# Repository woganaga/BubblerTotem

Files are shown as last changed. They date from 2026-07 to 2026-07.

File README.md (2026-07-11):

# BubblerTotem

Bubble-LED-Rage-Totem: a battery-powered LED totem / bubble machine — 6
stacked rings of 27 WS2811 LEDs (162 total, an unrolled 27×6 cylinder) plus a
bubble motor, driven by an ESP32-S3 with an INMP441 I2S microphone for
sound-reactive effects.

The firmware is a customized fork of
[WLED-MM (MoonModules)](https://github.com/MoonModules/WLED-MM), chosen for
its advanced audio visualizations.

## Project layout

| Path | Status | What it is |
|---|---|---|
| [`WLED-MM/`](WLED-MM/) | **active** | Firmware: WLED-MM fork (git submodule, branch `bubbler`). Totem customizations live in its `bubbler/` folder + usermods. |
| [`BubblerAnalyzer/`](BubblerAnalyzer/) | active | Offline audio/beat-detection analysis: pulls synchronized mic WAV + DSP metadata captures from the device over WiFi and diffs the pipeline against an offline replica. |
| [`docs/`](docs/) | active (port pending) | Web Bluetooth control app (GitHub Pages). Built for the v1 firmware; will be reworked once WLED-MM gets its BLE usermod. |
| [`archive/Bubbler-pio/`](archive/Bubbler-pio/) | retired | v1 custom firmware (PlatformIO): effects engine, palettes/presets, BLE protocol, beat detection. Superseded by the WLED-MM fork; kept as reference — the beat-detection work (comb tempo picker) and BLE chunk protocol are worth porting. |
| [`archive/BubblerIno/`](archive/BubblerIno/) | retired | Original Arduino IDE sketch (v0). |

## Working with the firmware submodule

```sh
git clone --recurse-submodules https://github.com/woganaga/BubblerTotem.git
cd BubblerTotem/WLED-MM
# copy bubbler/platformio_bubbler.sample.ini -> platformio_override.ini, add WiFi creds
pio run -e bubbler_totem
```

The submodule's `origin` is the `woganaga/WLED-MM` fork; `upstream` is
MoonModules. Custom work stays on the `bubbler` branch in low-collision
surfaces (`bubbler/`, usermods, the gitignored `platformio_override.ini`) so
upstream merges stay painless.

## Hardware map

| Function | GPIO |
|---|---|
| LED chain A (rings 3,2,1 — 81 px, WS2811 GRB) | 4 |
| LED chain B (rings 4,5,6 — 81 px) | 5 |
| INMP441 mic SCK / WS / SD | 44 / 7 / 8 |
| Bubble motor (planned) | 15 |
| RS485 command receiver (planned) | 1, 2, 42 |
| Onboard status LED (active low) | 21 |

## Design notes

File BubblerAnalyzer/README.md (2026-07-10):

# BubblerAnalyzer

Offline analysis of the totem's beat-detection pipeline, using synchronized
captures (raw mic WAV + per-frame DSP metadata CSV) pulled from the device
over WiFi.

## Workflow

1. Make sure the totem is on WiFi (`bubblertotem.local`) and, for musical
   tests, that the test material is playing at show volume.
2. Pull a capture:
   ```powershell
   .\capture.ps1 -Seconds 30          # clamped 5..30 by the firmware
   ```
   This triggers `/action/mic/record`, polls `/api/status`, and downloads
   `mic_recording.wav` + `mic_meta.csv` into `captures\<timestamp>\`.
3. Analyze (requires Python 3 + numpy + matplotlib):
   ```powershell
   py analyze.py captures\<timestamp> --bpm 160   # --bpm = ground truth, if known
   ```

`analyze.py` replicates the firmware pipeline (`AudioInput.cpp`: Hann FFT ->
log-compressed spectral flux -> conditioned onset envelope -> zero-mean
normalized autocorrelation -> harmonic-weighted tempo pick) on the recorded
audio and diffs it against what the device logged for the same instants:

- signal quality (peak/RMS dBFS, clipping, DC)
- onset envelope shape, offline vs device flux correlation
- ACF offline vs the device's final ACF snapshot
- tempo/confidence traces over time vs the device's, against ground truth

Plots land in the capture folder as `analysis.png`. Divergence between the
offline replica and the device log points at the broken stage; agreement
means the algorithm (not the implementation) needs work.

Captures are gitignored (a 30s WAV is ~1MB).

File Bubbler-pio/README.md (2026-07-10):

# Bubbler Totem

Firmware for a music-reactive LED totem: 6 stacked rings of 27 WS2811 LEDs
(162 total) driven by an ESP32-S3. The primary control interface is Web
Bluetooth (see below); WiFi/HTTP is a secondary, opt-in interface used
mainly for firmware updates.

This is the PlatformIO project. It was ported from the original Arduino IDE
sketch at `../BubblerIno`, which is no longer the active codebase.

## Hardware

- **MCU:** ESP32-S3 (8MB flash, dual-app OTA partition layout)
- **LEDs:** 6 rings × 27 WS2811 pixels, wired as two chains of 3 rings each
  - Pin 4: rings 3, 2, 1
  - Pin 5: rings 4, 5, 6
  - Physical layout/spacing lives in `Topology.*`; LED brightness is capped
    per-pixel (40%) and per-array (15%) in `Rings.cpp` to keep current draw
    in check.
- **Mic:** INMP441 I2S microphone
  - Pin 44: SCK, Pin 7: WS, Pin 8: SD
- **Status LED:** GPIO 21 (active low) — blinks in real time with the PLL
  beat clock once a tempo is tracked (raw onsets before that), so the beat
  tracker can be eyeballed against the music with no UI polling latency

## Features

- **Effects** (`EffectManager.*`, `Effects.*`): 12 original effects (Vertical/
  Horizontal Sweep, Alternate Flash, Chase, Spiral, Snow, Pinwheel, Colorwash,
  Fire, Confetti, Ripple) plus a **Beat Flash** test effect (whole array
  flashes and decays once per period — a metronome for the eyes; run it with
  Beat Sync at 1 beat/cycle to see exactly what the tempo tracker is doing)
  plus 8 effects ported from xLights (`XLFX.*`) that
  render onto the ring array treated as an unrolled 27×6 grid (Bars,
  Colorwash, Spirals, Pinwheel, Butterfly, Plasma, SingleStrand, Morph). Each
  effect keeps its own parameters (palette, speed, intensity, direction, and
  effect-specific controls) across activations.
- **Music reactivity** (`AudioInput.*`): a FreeRTOS task pinned to core 0 runs
  a 512-sample Hann-windowed FFT over the mic input, publishing a lock-free
  `AudioFeatures` snapshot — bass/mid/treble energy, smoothed volume, beat
  detection, and a BPM estimate (autocorrelation of the onset envelope + a
  PLL beat clock) with tap-tempo and ×2/÷2 override. **Beat Sync** (toggle on
  the Main tab) tempo-locks the running effect: once the tempo estimator is
  confidently locked, `EffectManager` stops feeding the effect real elapsed
  time and synthesizes its time input from the PLL beat clock, scaled so one
  full effect cycle spans exactly N beats (N auto-picked from ½/1/2/4/8 to
  best match the effect's speed setting, or fixed via the Beats-per-cycle
  buttons) with cycle boundaries landing on beats. The animation speeds up,
  slows down, and stays in phase with the music indefinitely — no per-effect
  changes needed, since each periodic effect is a pure function of its time
  argument and exposes its natural cycle length via
  `effectNativePeriodMs()`/`xlfxNativePeriodMs()`. Stochastic effects with no
  fixed loop (Snow, Fire, Confetti, Ripple, XL Butterfly, XL Plasma)
  free-run; while no confident tempo is detected, everything free-runs (with
  hysteresis so borderline confidence doesn't flap between modes). The Main
  tab shows a live readout of the lock state, and the status bar visualizes
  the tracker at a glance: detected-onset dot, a pulse dot that beats at the
  detected BPM (amber while unlocked, green when sync is locked — re-phased
  to the device's beat clock on every status poll), BPM + lock confidence,
  and a ♪×N badge showing the locked beats-per-cycle. A **Mic Recording** button
  (Settings tab, both transports) captures
  a fixed 10 seconds of raw mic audio to a `.wav` file on LittleFS, so you can
  judge how noisy the mic/preamp actually is by listening back. Triggering
  the recording works over BLE or WiFi, but the finished file (~320KB) is
  only downloadable over WiFi/HTTP — pushing that much data through the BLE
  chunk protocol above would be impractically slow.
- **Named palettes & saved effect presets** (`PaletteStore.*`,
  `CategoryStore.*`, `EffectPresetStore.*`): color palettes are created,
  edited, and deleted independently of any one effect, then *linked* to
  whichever effect is showing them (edit a palette and any effect currently
  using it updates live). A full effect configuration (type + palette link +
  params) can be named, categorized, and saved as a preset for one-tap
  recall later. All persisted to LittleFS.
- **Bluetooth control (primary interface)** (`BleServer.*`): a custom BLE
  GATT service (one write characteristic for commands, one notify
  characteristic for chunked JSON responses) exposes the full control
  surface — effects, palettes, presets, categories, mic calibration, WiFi
  on/off — to the standalone Web Bluetooth app at
  [`../docs/index.html`](../docs/index.html) (meant to be published somewhere
  HTTPS, e.g. GitHub Pages — Web Bluetooth requires a secure context and
  doesn't work from the device's own plain-HTTP page). **Safari on iOS/macOS
  does not support Web Bluetooth at all** (Apple's stated position, not a
  bug) — on iPhone, use a bridge browser like
  [Bluefy](https://apps.apple.com/app/bluefy-web-ble-browser/id1492822055)
  or WebBLE instead; desktop/Android Chrome and Edge work directly.
- **Web UI over WiFi** (`WebUI.*`, `WebApp.*`), a secondary interface served
  on port 80 once WiFi is on — a single-page app with the same Main/Effects/
  Saved/Palettes/Settings sections as the BLE app, plus a **Firmware Update**
  page under Settings that only shows up here (not over BLE, since pushing a
  multi-hundred-KB binary over BLE characteristics isn't practical).
- **WiFi** (`WifiSetup.*`): station mode, **off by default** — BLE is the
  primary interface, so the radio only comes on when explicitly enabled
  (toggle lives in the BLE app's Settings tab; the on/off choice persists to
  LittleFS across reboots). SSID/password live in `src/Secrets.h` (gitignored
  — copy `src/Secrets.h.example` to `src/Secrets.h` and fill in your network
  before building).
- **OTA updates** (`OTAUpdate.*`): `ArduinoOTA`, password-protected, an
  alternative to the WiFi web UI's Firmware Update page — both require WiFi
  to be turned on first.

## Building & flashing

Requires [PlatformIO](https://platformio.org/). This project uses the
[pioarduino](https://github.com/pioarduino/platform-espressif32) community
platform instead of the official `espressif32` platform, because it tracks
arduino-esp32 core 3.x — the official platform is still on core 2.x and
lacks the `ESP_I2S.h` API the mic driver depends on.

Before the first build, copy `src/Secrets.h.example` to `src/Secrets.h` and
fill in your WiFi SSID/password (that file is gitignored, so it won't be
committed).

```sh
pio run                 # build (default env: esp32-s3-devkitc-1-debug)
pio run -t upload       # build + flash over USB
pio run -t uploadfs     # push the LittleFS filesystem (mic settings, etc.)
pio device monitor      # serial monitor
```

There are three environments (`platformio.ini`):
- **`esp32-s3-devkitc-1-debug`** — the current default (`pio run` with no
  `-e` builds this). Same as the plain env, plus verbose BLE wire-protocol
  tracing (every chunk/ack/command) to the Serial monitor, gated behind
  `BUBBLER_BLE_DEBUG` (see `BLE_LOG` in `BleServer.cpp`).
- **`esp32-s3-devkitc-1`** — the quiet build, no BLE tracing. Once BLE is
  solid, build this explicitly (`pio run -e esp32-s3-devkitc-1 -t upload`),
  or flip `default_envs` in `platformio.ini` back to it.
- **`esp32-s3-devkitc-1-ota`** — OTA upload variant (extends the plain env).

Once the device is on the network, subsequent updates can go over OTA
(`espota`) or the WiFi web UI's Firmware Update page instead of USB. WiFi
being off by default means the very first flash (and any time it's been
turned off since) has to be over USB.

## Setting up the Bluetooth app

`../docs/index.html` (at the repo root, a sibling of this `Bubbler-pio`
folder — GitHub Pages' "/docs" option is relative to the repo root, not any
subfolder) is a standalone static page — it isn't served by the device.
Publish it somewhere HTTPS (Web Bluetooth requires that) and bookmark it on
your phone/laptop:

1. GitHub repo → **Settings → Pages** → Source: "Deploy from a branch" →
   branch `main`, folder `/docs` → Save.
2. GitHub gives you a URL like `https://<user>.github.io/BubblerTotem/`.
   Open it, tap **Connect**, and pick "BubblerTotem" from the Bluetooth
   device list.
3. On iPhone, do this inside Bluefy or WebBLE (not Safari) — see the Web UI
   note above.

## Project layout

```
../docs/index.html   standalone Web Bluetooth app, at the repo root (publish via GitHub Pages)
platformio.ini       build config (board, pioarduino platform, lib_deps)
partitions.csv        8MB flash partition table (dual OTA app slots + LittleFS)
src/
  main.cpp            setup()/loop()
  Rings.*              LED buffer, ring addressing, brightness caps
  Topology.*            physical ring spacing/geometry
  EffectManager.*       active effect + per-effect param/palette-link storage/dispatch
  EffectUI.*            per-effect-type UI capability table, shared by WebUI and BleServer
  Effects.*             original effects
  XLFX.*                xLights-derived effects
  Palette.h / Color.h / EffectParams.h   shared color/param types
  PaletteStore.*         named/saved color palettes (LittleFS)
  CategoryStore.*        named categories for saved effects (LittleFS)
  EffectPresetStore.*     named/saved effect configurations (LittleFS)
  AudioInput.*          I2S mic capture, FFT/DSP task, beat/BPM detection
  BleServer.*           Web Bluetooth GATT service + JSON command dispatch (primary interface)
  WebUI.* / WebApp.*     WiFi HTTP server + single-page app (secondary interface)
  WifiSetup.*           WiFi station connect, off by default, persisted on/off toggle
  OTAUpdate.*           ArduinoOTA
```

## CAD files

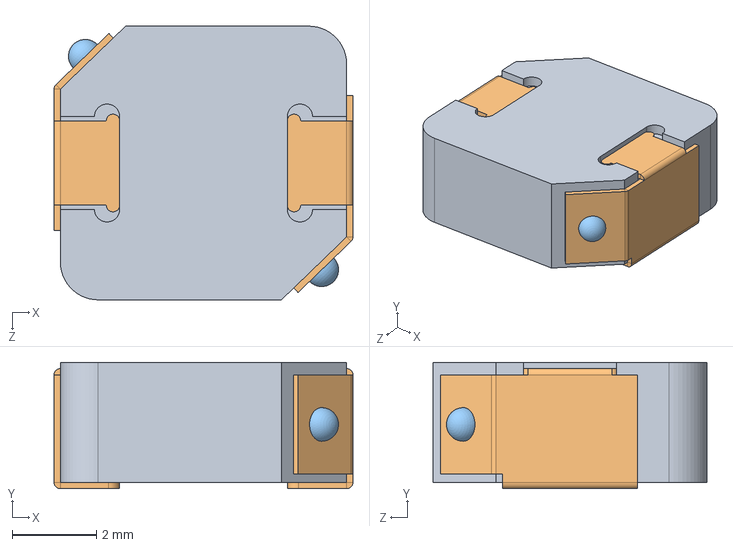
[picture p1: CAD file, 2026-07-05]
BubblerMain/SPM6530T-3R3M.step
7.10 x 3.00 x 6.50 mm

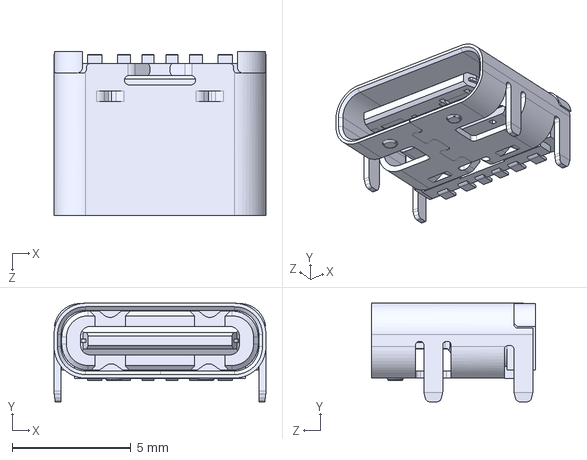
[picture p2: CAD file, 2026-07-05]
BubblerMain/UJC-H-G-SMT-P6-TR.step
8.94 x 4.16 x 6.90 mm

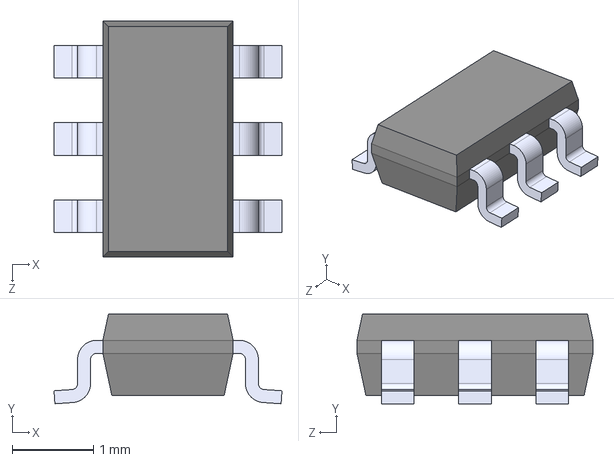
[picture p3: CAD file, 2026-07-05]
BubblerMain/TPS565201DDCR.step
2.80 x 1.10 x 2.90 mm

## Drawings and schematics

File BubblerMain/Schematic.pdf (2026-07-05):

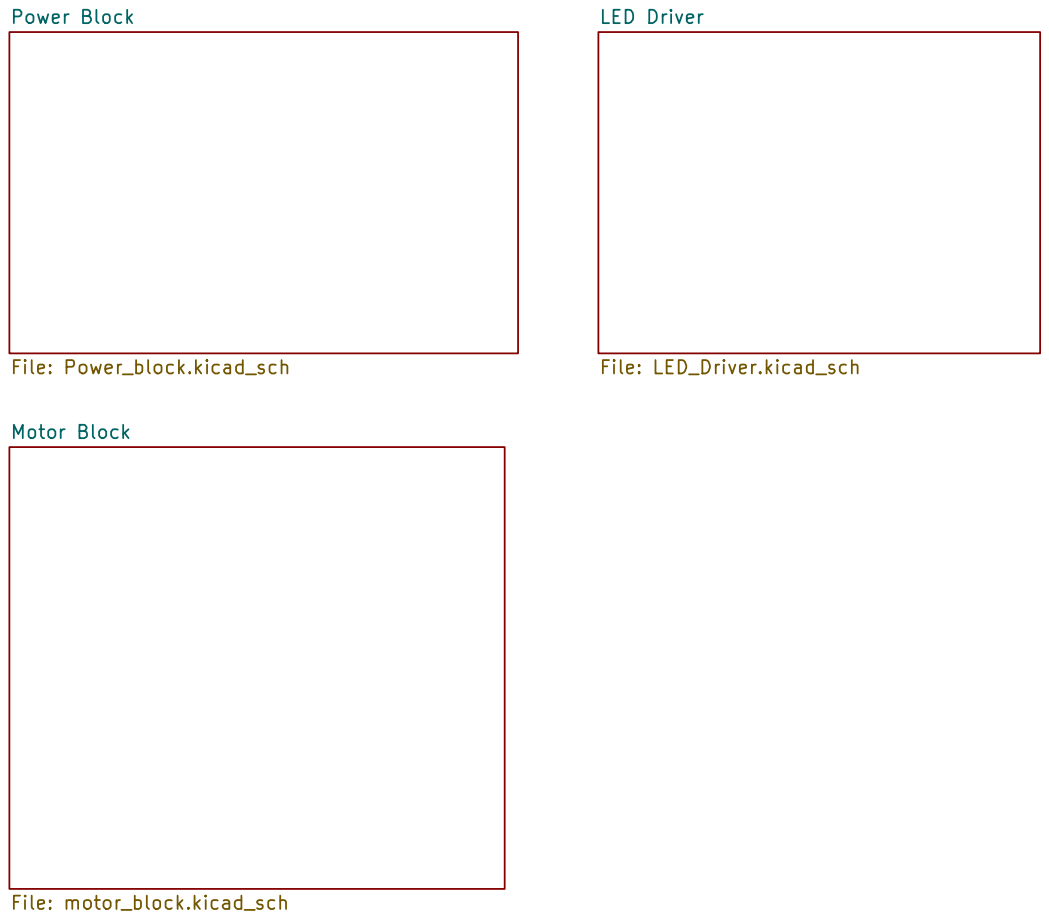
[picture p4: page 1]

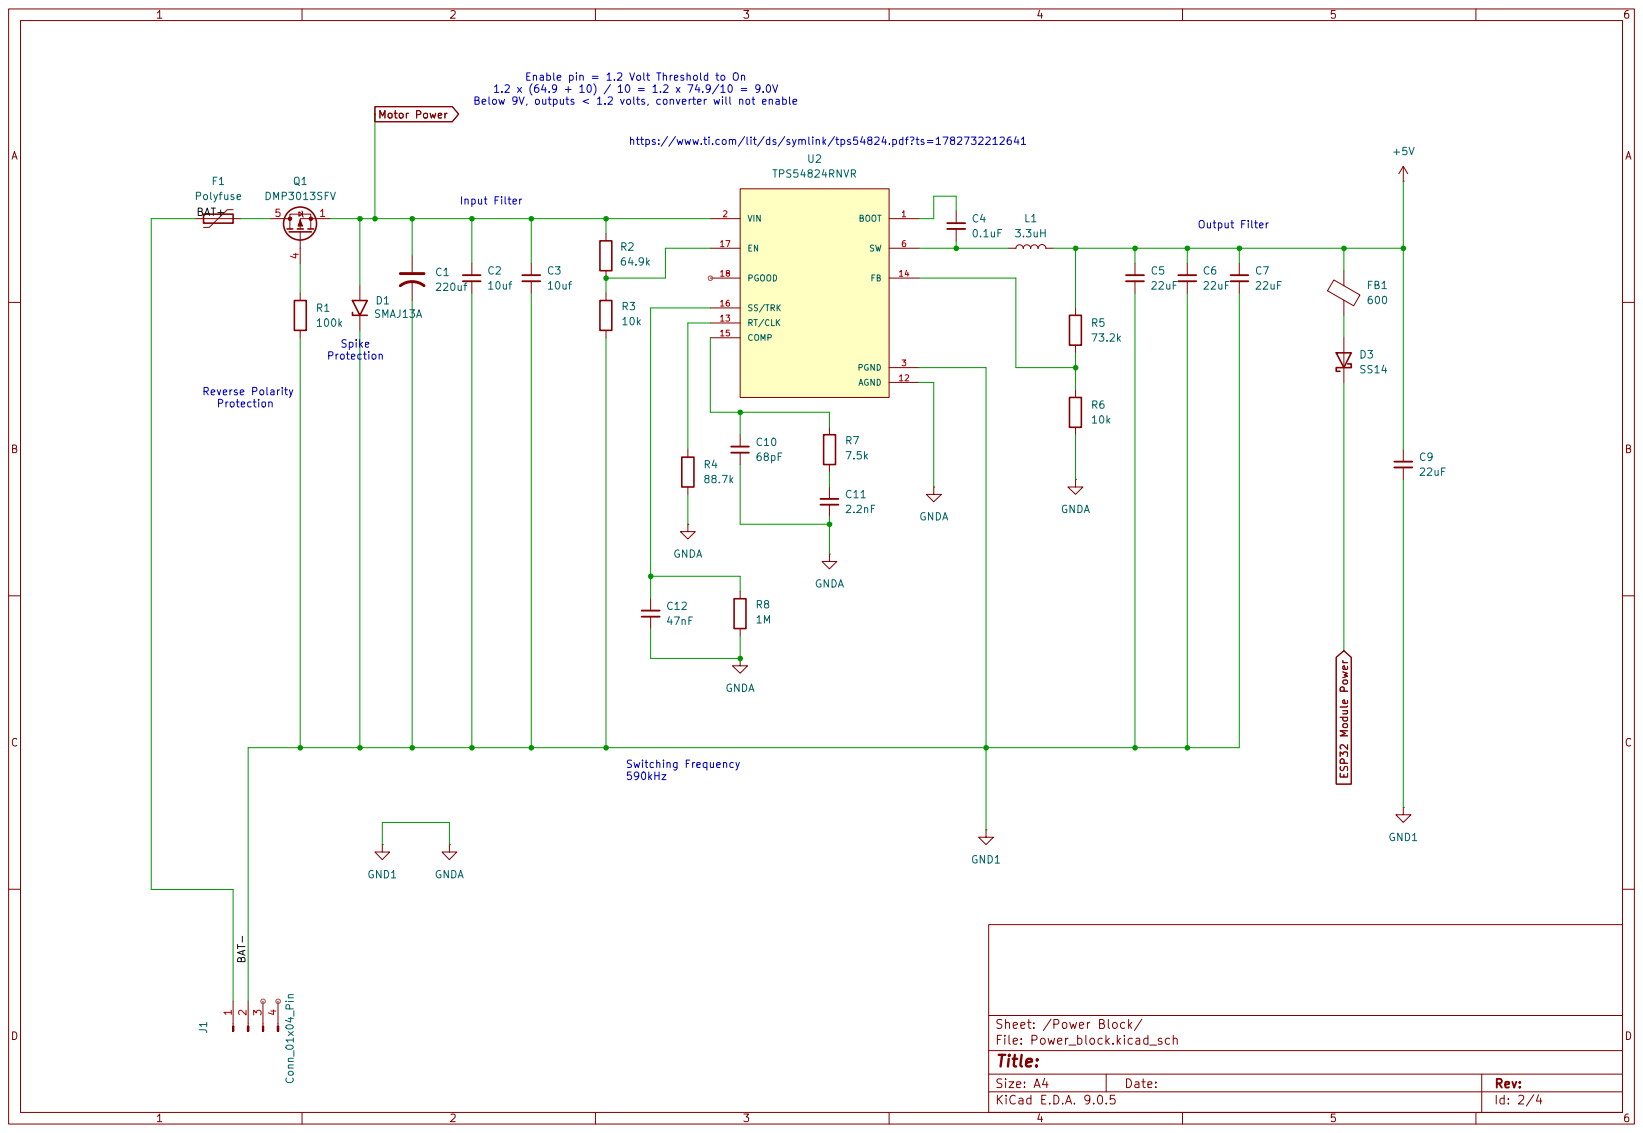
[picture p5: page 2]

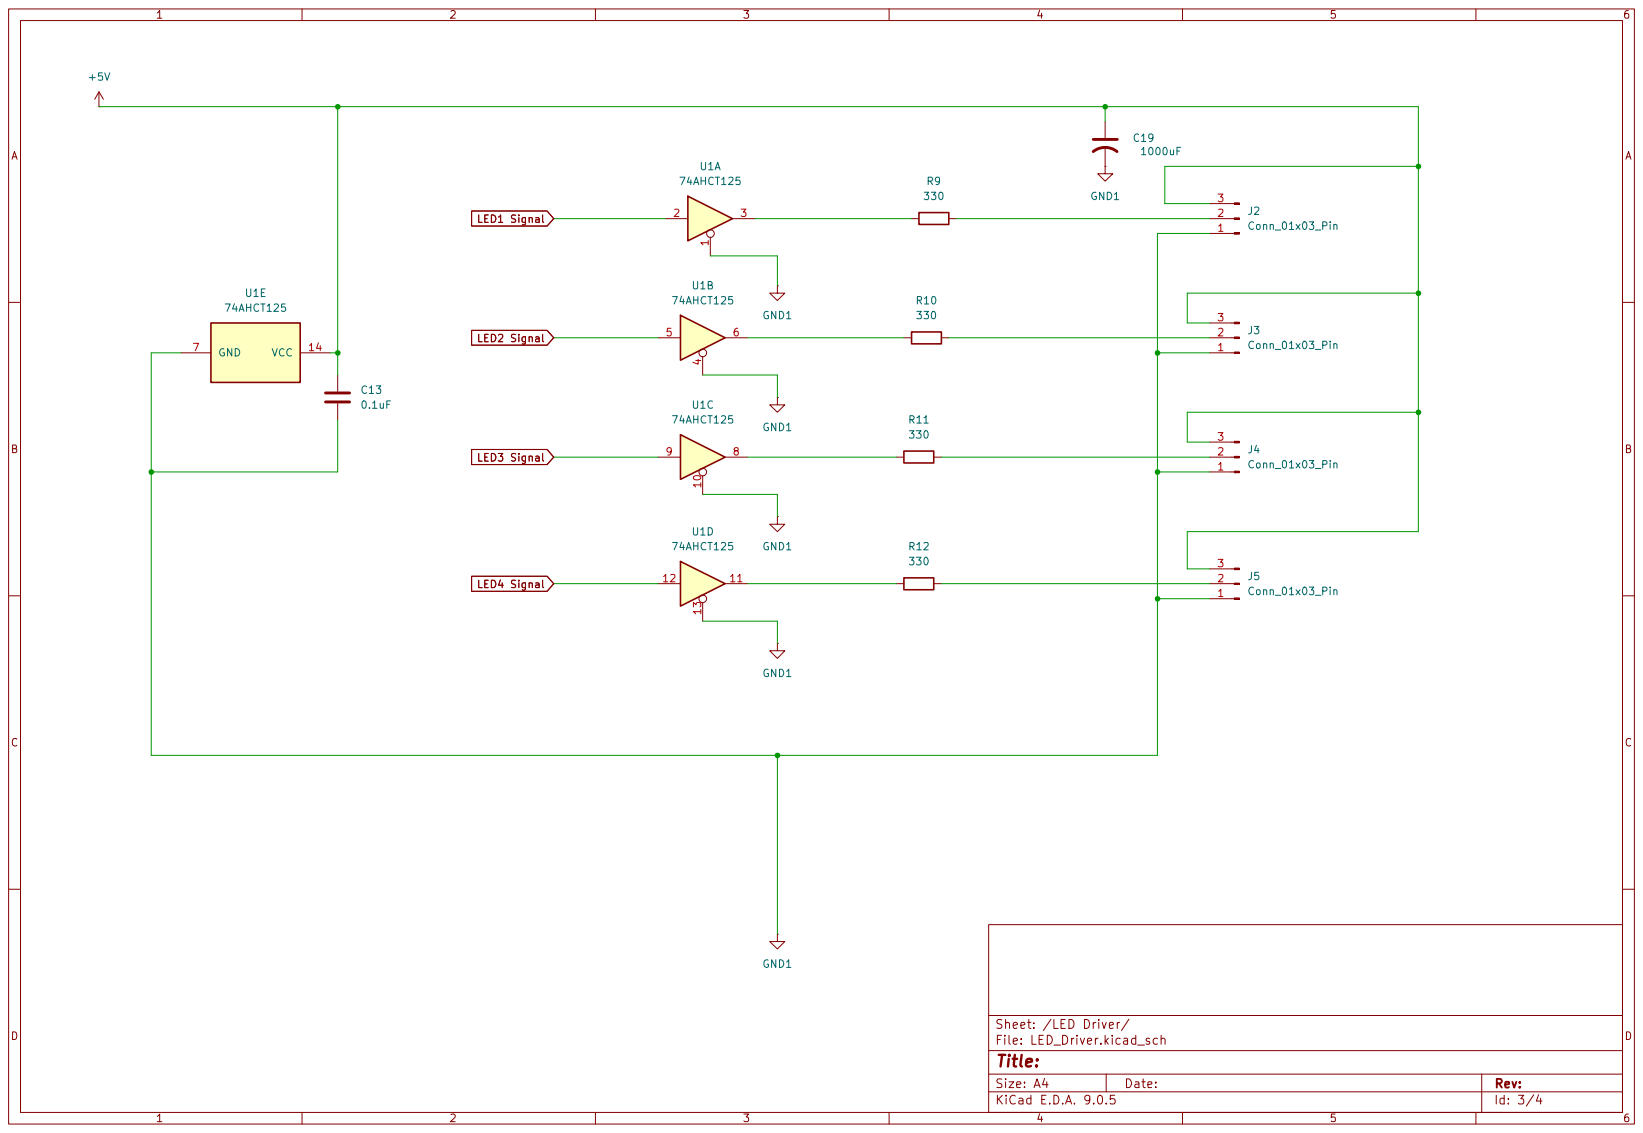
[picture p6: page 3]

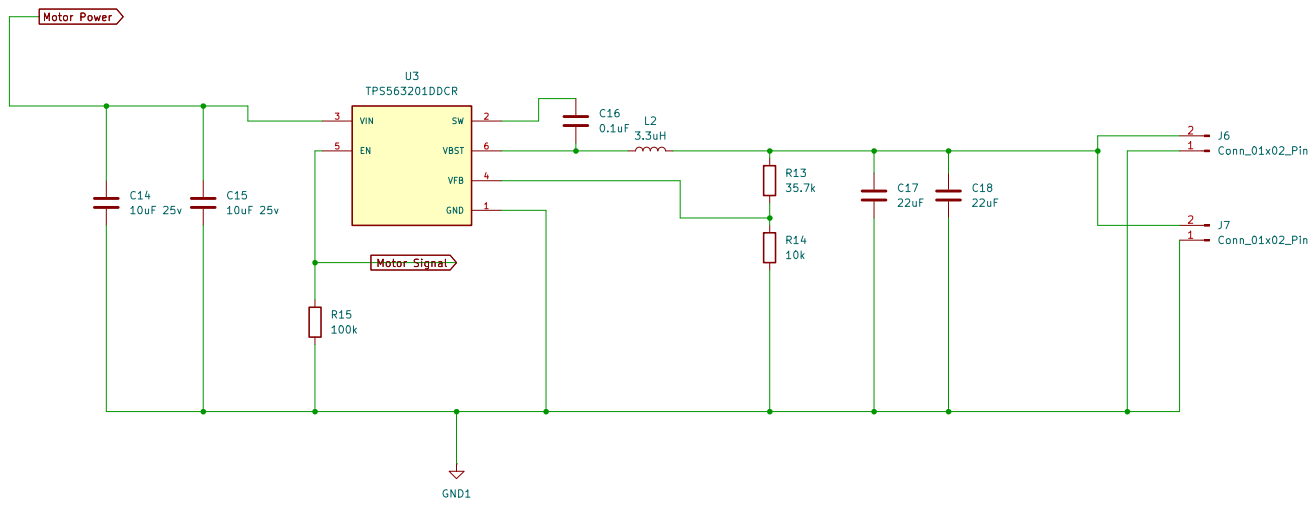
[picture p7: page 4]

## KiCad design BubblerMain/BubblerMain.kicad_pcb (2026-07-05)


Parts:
C13: 0.1uF; C_1206_3216Metric_Pad1.33x1.80mm_HandSolder
C19: 1000uF; CP_Elec_10x10
J2, J3, J4, J5: Conn_01x03_Pin; JST_XH_B3B-XH-AM_1x03_P2.50mm_Vertical
R9, R10, R11, R12: 330; R_1206_3216Metric_Pad1.30x1.75mm_HandSolder
U1: 74AHCT125; SOIC-14_3.9x8.7mm_P1.27mm; LCSC C2675672

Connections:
+5V: C13.1, C19.1, J2.3, J3.3, J4.3, J5.3, U1.14 (VCC); also elsewhere on the board
GND1: C13.2, C19.2, J2.1, J3.1, J4.1, J5.1, U1.1, U1.4, U1.7 (GND), U1.10, U1.13; also elsewhere on the board
LED1 Signal: U1.2; also elsewhere on the board
LED2 Signal: U1.5; also elsewhere on the board
LED3 Signal: U1.9; also elsewhere on the board
LED4 Signal: U1.12; also elsewhere on the board
unnamed: J2.2, R9.1
unnamed: J3.2, R10.1
unnamed: J4.2, R11.1
unnamed: J5.2, R12.1
unnamed: R9.2, U1.3
unnamed: R10.2, U1.6
unnamed: R11.2, U1.8
unnamed: R12.2, U1.11


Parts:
5V2: TestPoint; TestPoint_Pad_2.0x2.0mm
C1: 220uf; CP_Elec_10x10
C2, C3: 10uf; C_1206_3216Metric_Pad1.33x1.80mm_HandSolder
C4: 0.1uF; C_1210_3225Metric_Pad1.33x2.70mm_HandSolder
C5, C6: 22uF; C_1210_3225Metric_Pad1.33x2.70mm_HandSolder
C7: 0.1uF; C_1206_3216Metric_Pad1.33x1.80mm_HandSolder
D1: SMAJ13A; D_SMA
F1: Polyfuse; Fuse_1812_4532Metric
GND1: TestPoint; TestPoint_Pad_2.0x2.0mm
J1: Conn_01x04_Pin; JST_XH_B2B-XH-AM_1x02_P2.50mm_Vertical
L1: 3.3uH; IND_SPM6530T-3R3M; PARTREV N/A; LCSC C76856
Q1: DMP3013SFV; Diodes_PowerDI3333-8; LCSC C264098
R1, R2: 100k; R_1206_3216Metric_Pad1.30x1.75mm_HandSolder
R5: 54.9k; R_1206_3216Metric_Pad1.30x1.75mm_HandSolder
R6: 10k; R_1206_3216Metric_Pad1.30x1.75mm_HandSolder
U9: TPS565201DDCR; SOT95P280X110-6N; LCSC C327676

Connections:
+5V: 5V2.1, C5.1, C6.1, L1.2, R5.1; also elsewhere on the board
/Power Block/BAT+: F1.2, J1.1
/Power Block/Fuse-Pol: F1.1, Q1.5 (D)
GND1: C1.2, C2.2, C3.2, C5.2, C6.2, C7.2, D1.1 (A1), GND1.1, J1.2, R1.2, R6.2, U9.1 (GND); also elsewhere on the board
Motor Power: C1.1, C2.1, C3.1, C7.1, D1.2 (A2), Q1.1 (S), Q1.2 (S), Q1.3 (S), R2.1, U9.3 (VIN); also elsewhere on the board
unnamed: Q1.4 (G), R1.1
unnamed: R2.2, U9.5 (EN)
unnamed: C4.1, L1.1, U9.2 (SW)
unnamed: C4.2, U9.6 (VBST)
unnamed: R5.2, R6.1, U9.4 (VFB)

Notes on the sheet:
Output Filter
Input Filter
Spike Protection
Reverse Polarity Protection


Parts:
3.3V1, 5V1: LED; LED_1206_3216Metric_Pad1.42x1.75mm_HandSolder
3v3: TestPoint; TestPoint_Pad_2.0x2.0mm
C8, C21: 1uF; C_1206_3216Metric_Pad1.33x1.80mm_HandSolder
C9, C22: 22uF; C_1210_3225Metric_Pad1.33x2.70mm_HandSolder
C20: 0.1uF; C_1206_3216Metric_Pad1.33x1.80mm_HandSolder
D2, D3: SS14; D_SMA
FB1: 600; L_1206_3216Metric
J8: USB_C_Receptacle; USB_C_Receptacle_HCTL_HC-TYPE-C-16P-01A
J9: Conn_01x08_Pin; PinHeader_1x08_P2.54mm_Vertical
J12: Conn_01x08_Pin; PinHeader_1x04_P2.54mm_Vertical
MOTOR1: LED; LED_1206_3216Metric_Pad1.42x1.75mm_HandSolder
R16, R17: 5.1k; R_1206_3216Metric_Pad1.30x1.75mm_HandSolder
R18, R19: 10k; R_1206_3216Metric_Pad1.30x1.75mm_HandSolder
R20, R22: 1.5k; R_1206_3216Metric_Pad1.30x1.75mm_HandSolder
R21, R23, R26: 680; R_1206_3216Metric_Pad1.30x1.75mm_HandSolder
SW1, SW2: SW_Push; SW_SPST_PTS645Sx43SMTR92
SW3: LED; LED_1206_3216Metric_Pad1.42x1.75mm_HandSolder
U4: ESP32-S3-WROOM-1; ESP32-S3-WROOM-2; LCSC C2913198
U5: AP2112K-3.3; SOT-23-5; LCSC C23380830
U6: USBLC6-2SC6; SOT-23-6; LCSC C2827654
USB1: LED; LED_1206_3216Metric_Pad1.42x1.75mm_HandSolder

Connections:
+3V3: 3v3.1, C20.1, C22.1, J12.3, R18.1, R19.1, R21.1, U4.2 (3V3), U5.5 (VOUT); also elsewhere on the board
+5V: FB1.1, J12.4; also elsewhere on the board
/ESP32/A6: J8.A6 (D+), J8.B6 (D+), U6.4 (I/O2)
/ESP32/A7: J8.A7 (D-), J8.B7 (D-), U6.6 (I/O1)
/ESP32/GPIO8: J9.1, U4.12 (IO8)
/ESP32/GPIO9: J9.2, U4.17 (IO9)
/ESP32/GPIO10: J9.3, U4.18 (IO10)
/ESP32/GPIO11: J9.4, U4.19 (IO11)
/ESP32/GPIO12: J9.5, U4.20 (IO12)
/ESP32/GPIO13: J9.6, U4.21 (IO13)
/ESP32/GPIO14: J9.7, U4.22 (IO14)
/ESP32/GPIO21: J9.8, U4.23 (IO21)
/ESP32/SW_LED: R23.1, U4.25 (IO48)
/ESP32/VBUS: D2.2 (A), J8.A4 (VBUS), J8.A9 (VBUS), J8.B4 (VBUS), J8.B9 (VBUS), R22.1, U6.5 (VBUS)
GND1: 3.3V1.1 (K), 5V1.1 (K), C8.2, C9.2, C20.2, C21.2, C22.2, J8.A1 (GND), J8.A12 (GND), J8.B1 (GND), J8.B12 (GND), J12.1, MOTOR1.1 (K), R16.2, R17.2, SW1.1, SW2.2, SW3.1 (K), U4.1 (GND), U4.40 (GND), U4.41 (GND), U5.2 (GND), U6.2 (GND), USB1.1 (K); also elsewhere on the board
I2S_SCK: U4.9 (IO16); also elsewhere on the board
I2S_SD: U4.11 (IO18); also elsewhere on the board
I2S_WS: U4.10 (IO17); also elsewhere on the board
LED1 Signal: U4.4 (IO4); also elsewhere on the board
LED2 Signal: U4.5 (IO5); also elsewhere on the board
LED3 Signal: U4.6 (IO6); also elsewhere on the board
LED4 Signal: U4.7 (IO7); also elsewhere on the board
Motor Power: J12.2; also elsewhere on the board
Motor Signal: R26.1, U4.8 (IO15); also elsewhere on the board
unnamed 26: 3.3V1.2 (A), R21.2; also elsewhere on the board
unnamed 27: 5V1.2 (A), R20.2; also elsewhere on the board
unnamed: C8.1, C9.1, D2.1 (K), D3.1 (K), R20.1, U5.1 (VIN), U5.3 (EN)
unnamed: D3.2 (A), FB1.2
unnamed: MOTOR1.2 (A), R26.2
unnamed 45: R23.2, SW3.2 (A); also elsewhere on the board
unnamed: C21.1, R18.2, SW1.2, U4.3 (EN)
unnamed: R19.2, SW2.1, U4.27 (IO0)
unnamed: U4.14 (USB_D+/IO20), U6.3 (I/O2)
unnamed: U4.13 (USB_D-/IO19), U6.1 (I/O1)
unnamed 57: R22.2, USB1.2 (A); also elsewhere on the board
RS485_DE: U4.35 (MTMS/IO42); also elsewhere on the board
RS485_RX: U4.38 (IO2); also elsewhere on the board
RS485_TX: U4.39 (IO1); also elsewhere on the board

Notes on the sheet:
Expansion Header for future use


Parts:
C8, C21: 1uF
C20: 0.1uF
C22: 22uF
D2: SS14
D4, D5, D6, D7: LED
J8: USB_C_Receptacle
R16, R17: 5.1k
R18, R19: 10k
R20, R22: 1.5k
R21, R23: 680
SW1, SW2: SW_Push
U4: ESP32-S3-WROOM-1; ESP32-S3-WROOM-2
U5: AP2112K-3.3; SOT-23-5
U6: USBLC6-2SC6; SOT-23-6

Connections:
+3V3: C20.1, C22.1, R18.1, R19.1, R21.1, U4.2 (3V3), U5.5 (VOUT); also elsewhere on the board
/ESP32/A6: J8.A6 (D+), J8.B6 (D+), U6.4 (I/O2)
/ESP32/A7: J8.A7 (D-), J8.B7 (D-), U6.6 (I/O1)
/ESP32/GPIO8: U4.12 (IO8); also elsewhere on the board
/ESP32/GPIO9: U4.17 (IO9); also elsewhere on the board
/ESP32/GPIO10: U4.18 (IO10); also elsewhere on the board
/ESP32/GPIO11: U4.19 (IO11); also elsewhere on the board
/ESP32/GPIO12: U4.20 (IO12); also elsewhere on the board
/ESP32/GPIO13: U4.21 (IO13); also elsewhere on the board
/ESP32/GPIO14: U4.22 (IO14); also elsewhere on the board
/ESP32/GPIO21: U4.23 (IO21); also elsewhere on the board
/ESP32/SW_LED: R23.1, U4.25 (IO48)
/ESP32/VBUS: D2.2 (A), J8.A4 (VBUS), J8.A9 (VBUS), J8.B4 (VBUS), J8.B9 (VBUS), R22.1, U6.5 (VBUS)
GND1: C8.2, C20.2, C21.2, C22.2, D4.1 (K), D5.1 (K), D6.1 (K), D7.1 (K), J8.A1 (GND), J8.A12 (GND), J8.B1 (GND), J8.B12 (GND), R16.2, R17.2, SW1.1, SW2.2, U4.1 (GND), U4.40 (GND), U4.41 (GND), U5.2 (GND), U6.2 (GND); also elsewhere on the board
I2S_SCK: U4.9 (IO16); also elsewhere on the board
I2S_SD: U4.11 (IO18); also elsewhere on the board
I2S_WS: U4.10 (IO17); also elsewhere on the board
LED1 Signal: U4.4 (IO4); also elsewhere on the board
LED2 Signal: U4.5 (IO5); also elsewhere on the board
LED3 Signal: U4.6 (IO6); also elsewhere on the board
LED4 Signal: U4.7 (IO7); also elsewhere on the board
Motor Signal: U4.8 (IO15); also elsewhere on the board
unnamed 26: D5.2 (A), R21.2; also elsewhere on the board
unnamed 27: D4.2 (A), R20.2; also elsewhere on the board
unnamed 28: C8.1, D2.1 (K), R20.1, U5.1 (VIN), U5.3 (EN); also elsewhere on the board
unnamed 45: D7.2 (A), R23.2; also elsewhere on the board
unnamed: C21.1, R18.2, SW1.2, U4.3 (EN)
unnamed: R19.2, SW2.1, U4.27 (IO0)
unnamed: U4.14 (USB_D+/IO20), U6.3 (I/O2)
unnamed: U4.13 (USB_D-/IO19), U6.1 (I/O1)
unnamed 57: D6.2 (A), R22.2; also elsewhere on the board
RS485_DE: U4.35 (MTMS/IO42); also elsewhere on the board
RS485_RX: U4.38 (IO2); also elsewhere on the board
RS485_TX: U4.39 (IO1); also elsewhere on the board


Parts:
C14, C15: 10uF 25v; C_1206_3216Metric_Pad1.33x1.80mm_HandSolder
C16: 0.1uF; C_1206_3216Metric_Pad1.33x1.80mm_HandSolder
C17, C18: 22uF; C_1210_3225Metric_Pad1.33x2.70mm_HandSolder
J6, J7: Conn_01x02_Pin; JST_XH_B2B-XH-AM_1x02_P2.50mm_Vertical
L2: 3.3uH; IND_SPM6530T-3R3M; PARTREV N/A; LCSC C76856
R13: 35.7k; R_1206_3216Metric_Pad1.30x1.75mm_HandSolder
R14: 10k; R_1206_3216Metric_Pad1.30x1.75mm_HandSolder
R15: 100k; R_1206_3216Metric_Pad1.30x1.75mm_HandSolder
U3: TPS563201DDCR; TSOT-23-6_HandSoldering; PARTREV December 2015; LCSC C116592

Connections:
GND1: C14.2, C15.2, C17.2, C18.2, J6.1, J7.1, R14.2, R15.2, U3.1 (GND); also elsewhere on the board
Motor Power: C14.1, C15.1, U3.3 (VIN); also elsewhere on the board
Motor Signal: R15.1, U3.5 (EN); also elsewhere on the board
unnamed: C17.1, C18.1, J6.2, J7.2, L2.2, R13.1
unnamed: C16.1, L2.1, U3.2 (SW)
unnamed: C16.2, U3.6 (VBST)
unnamed: R13.2, R14.1, U3.4 (VFB)


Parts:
C23, C24: 0.1uF; C_1206_3216Metric_Pad1.33x1.80mm_HandSolder
C25: 4.7uF; C_1206_3216Metric_Pad1.33x1.80mm_HandSolder
J10: Conn_01x04_Pin; JST_XH_B2B-XH-AM_1x02_P2.50mm_Vertical
J11: Conn_01x08_Pin; JST_XH_B8B-XH-AM_1x08_P2.50mm_Vertical
R24, R29: 100k; R_1206_3216Metric_Pad1.30x1.75mm_HandSolder
R25: 120; R_1206_3216Metric_Pad1.30x1.75mm_HandSolder
R27, R28: 33; R_1206_3216Metric_Pad1.30x1.75mm_HandSolder
U7: THVD1400D; SOIC-8_3.9x4.9mm_P1.27mm; LCSC C3235232
U8: SM712; SOT23-WIDE; LCSC C502564

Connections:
+3V3: C23.1, C24.1, C25.1, J11.1, U7.8 (VCC); also elsewhere on the board
GND1: C23.2, C24.2, C25.2, J11.2, J11.4, J11.6, J11.8, R24.2, R29.2, U7.5 (GND), U8.3; also elsewhere on the board
I2S_SCK: R27.2; also elsewhere on the board
I2S_SD: J11.7, R29.1; also elsewhere on the board
I2S_WS: R28.2; also elsewhere on the board
unnamed: J10.1, R25.2, U7.7 (B), U8.1
unnamed: J10.2, R25.1, U7.6 (A), U8.2
unnamed: J11.3, R27.1
unnamed: J11.5, R28.1
RS485_DE: R24.1, U7.2 (~RE), U7.3 (DE); also elsewhere on the board
RS485_RX: U7.1 (RO); also elsewhere on the board
RS485_TX: U7.4 (DI); also elsewhere on the board

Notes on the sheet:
RS485 Transceiver
INMP441 Module Header
INMP441 Module will be on an 8-10 inch lead from the PCB Connected with CAT5 twisted pair. Ground/Signal for each twisted pair.

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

Board: 4 copper layers, 72.0 x 66.0 mm, 85 parts (0 on the bottom side), 63 nets.

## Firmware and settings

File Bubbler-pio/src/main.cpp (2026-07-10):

#include <Arduino.h>
#include <FastLED.h>
#include "Rings.h"
#include "PaletteStore.h"
#include "CategoryStore.h"
#include "EffectPresetStore.h"
#include "EffectManager.h"
#include "WifiSetup.h"
#include "WebUI.h"
#include "BleServer.h"
#include "OTAUpdate.h"
#include "AudioInput.h"

void setup() {
  Serial.begin(115200);
  // On ESP32-S3's native USB CDC (ARDUINO_USB_CDC_ON_BOOT=1, set in
  // platformio.ini), Serial.print()/printf() blocks waiting for a host to
  // actually read the data - with no serial monitor attached, every one of
  // the many BLE debug prints in BleServer.cpp would stall the calling
  // task (the NimBLE host task), which looked exactly like "BLE only works
  // with the monitor open". A 0ms tx timeout makes writes never block: if
  // nobody's reading, the bytes are just dropped instead of stalling.
  Serial.setTxTimeoutMs(0);
  delay(200); // let the USB-serial connection settle before the first print
  Serial.println("\nBubblerTotem booting...");

  paletteStoreInit();
  categoryStoreInit();
  presetStoreInit();
  effectManagerInit();
  ringsInit();
  wifiInit();  // off by default; BLE (below) is the primary interface
  webUIInit();
  bleServerInit();
  otaInit();
  audioInit();
}

void loop() {
  webUIHandle();
  bleServerHandle();
  otaHandle();
  audioUpdate(millis());

  if (audioCalibrationActive()) {
    setAll(audioBeatActive() ? CRGB::White : CRGB::Black);
    showAll();
  } else {
    runActiveEffect(millis());
  }
}

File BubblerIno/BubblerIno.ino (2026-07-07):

#include <FastLED.h>
#include "Rings.h"
#include "EffectManager.h"
#include "WifiSetup.h"
#include "WebUI.h"
#include "OTAUpdate.h"
#include "AudioInput.h"

void setup() {
  ringsInit();
  wifiInit();
  webUIInit();
  otaInit();
  audioInit();
}

void loop() {
  webUIHandle();
  otaHandle();
  audioUpdate(millis());

  if (audioCalibrationActive()) {
    setAll(audioBeatActive() ? CRGB::White : CRGB::Black);
    showAll();
  } else {
    runActiveEffect(millis());
  }
}

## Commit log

2026-07-05 small udpates
    [BubblerMain.kicad_pcb]
2026-07-05 flooded power plane
    [BubblerMain-B_Courtyard.gbr, BubblerMain-B_Cu.gbr, BubblerMain-B_Fab.gbr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]
2026-07-05 BubblerRemote initial commit
    [BubblerRemote.kicad_pcb, BubblerRemote.kicad_sch, Power_block.kicad_sch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]
2026-07-10 ported to pio
    [partitions.csv]
2026-07-10 Beat sync v2: tempo-lock effect cycles to the PLL beat clock
    Replaces the v1 restart-on-onset anchor with true tempo-locking: once the
    tempo estimator is confidently locked, EffectManager synthesizes the active
    effect's time input from the beat clock (beatCount + beatPhase, extrapolated
    between DSP frames) so one full effect cycle spans exactly N beats and cycle
    boundaries land on beats.
    - Effects.cpp/XLFX.cpp: effectNativePeriodMs()/xlfxNativePeriodMs() expose
    each periodic effect's full visual cycle length; stochastic effects
    (Snow, Fire, Confetti, Ripple, Butterfly, Plasma) return 0 and free-run
    - Beats per cycle: Auto (log-closest of 1/2..8 to the speed setting, with
    switching hys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
    [AudioInput.cpp, EffectManager.cpp, Effects.cpp]
2026-07-10 Beat/tempo visualization: status bar upgrades, Beat Flash effect, GPIO21 LED
    - Status bar (both frontends): tempo pulse dot that beats at the detected
    BPM between polls (CSS animation re-phased to the device beat clock via a
    new beatPhase status field; amber tracking, green when sync locked), BPM +
    lock confidence readout, and a sync badge showing beats-per-cycle
    - New Beat Flash test effect: whole array flashes and decays once per
    period, one palette color per flash, Flash Length % control - run it with
    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
2026-07-10 Rework tempo estimation: fix confidence ceiling, 160 BPM, phantom silence BPM
    All three reported symptoms traced to specific defects:
    - Confidence capped ~25%: the ACF ran on the all-positive onset envelope
    with its DC left in, flattening every lag to ~mean^2. Now zero-mean,
    variance-normalized - r is a true correlation and the interpolated peak
    value IS the confidence.
    - ~110 BPM detected in silence: the decaying-peak flux normalizer
    stretched mic self-noise to full scale, and the narrow 120-BPM prior
    picked a winner from the flat noise ACF. Now log-compressed flux with
    local-mean subtraction + rectification (no AGC), plus hold-then-release:
    ~4s below 15% confidence drops the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
    [AudioInput.cpp]
2026-07-10 Add synchronized DSP metadata capture + BubblerAnalyzer offline tooling
    Firmware: while a mic recording runs, also log one CSV row per DSP frame
    (flux, conditioned onset, band levels, beat flag, bpm, confidence, PLL
    phase) plus a final ACF snapshot to /mic_meta.csv, downloadable over WiFi
    like the WAV. Recording length is now a parameter (5..30s, flash-limited).
    BubblerAnalyzer/: capture.ps1 triggers a recording over HTTP, polls, and
    pulls both files; analyze.py replicates the firmware pipeline on the WAV,
    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
2026-07-10 Replace tempo picker with fractional-lag comb search + half-lag penalty
    Metronome capture analysis (BubblerAnalyzer) showed the integer-lag picker
    fails structurally at fast tempi: 160 BPM = lag 11.72 at 31.25 fps, so its
    correlation splits across bins 11/12 and integer evaluation of its
    harmonics (2*12=24 vs true 23.4) misses the real peaks, while the
    half-tempo impostor at lag 23 sits on-peak everywhere and wins - the
    device slid 157 -> ~88 BPM live while confidence stayed high.
    - Comb search over a continuous 0.5-BPM grid, reading the ACF at
    interpolated fractional lags (1x/2x/3x/4x weighted), so fractional beat
    periods get full harmonic credit
    - Half-lag penalty: positive correlatio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
    [AudioInput.cpp]
2026-07-10 Add click_rate.py: pipeline-independent ground-truth tempo measurement
    Measures a metronome capture true click rate at sample precision from the
    raw WAV (envelope peak-pick -> inter-click intervals), so the reference
    tempo of a capture never has to be assumed. The 2026-07-10 metronome
    capture measures exactly 160.00 BPM median (+/-6.7ms jitter).
2026-07-11 Archive Bubbler-pio v1 firmware (completes a6e9d08 restructure)
    [partitions.csv]
2026-07-12 WLED-MM: bubble motor relay on GPIO6 + quickload toggle
2026-07-12 WLED-MM: I2S mic pin swap (SD=7, WS=8)
2026-07-12 WLED-MM: Flow group bubbler integration + 20s durations
2026-07-12 WLED-MM: UI status bar for effect + bubble timer
2026-07-12 Web-BLE remote page + BLE bridge usermod (firmware side disabled)
    docs/index.html rewritten as the simple Web Bluetooth remote:
    brightness slider, live status (effect / playlist / bubbler), one
    button per playlist, Effects Off, and Bubbles On/Off/Timer. Talks to
    the bubbler_ble usermod GATT service; needs that usermod enabled in
    firmware (currently off pending WiFi-coexistence validation).
2026-07-12 WLED-MM: Stop Playlist button in preset seeder
2026-07-13 Wash playlist + stop-playlist fix; remote page: Wash + Stop buttons
2026-07-14 Bubbler timer-only control, playlist name in status bar; archive stray build file
